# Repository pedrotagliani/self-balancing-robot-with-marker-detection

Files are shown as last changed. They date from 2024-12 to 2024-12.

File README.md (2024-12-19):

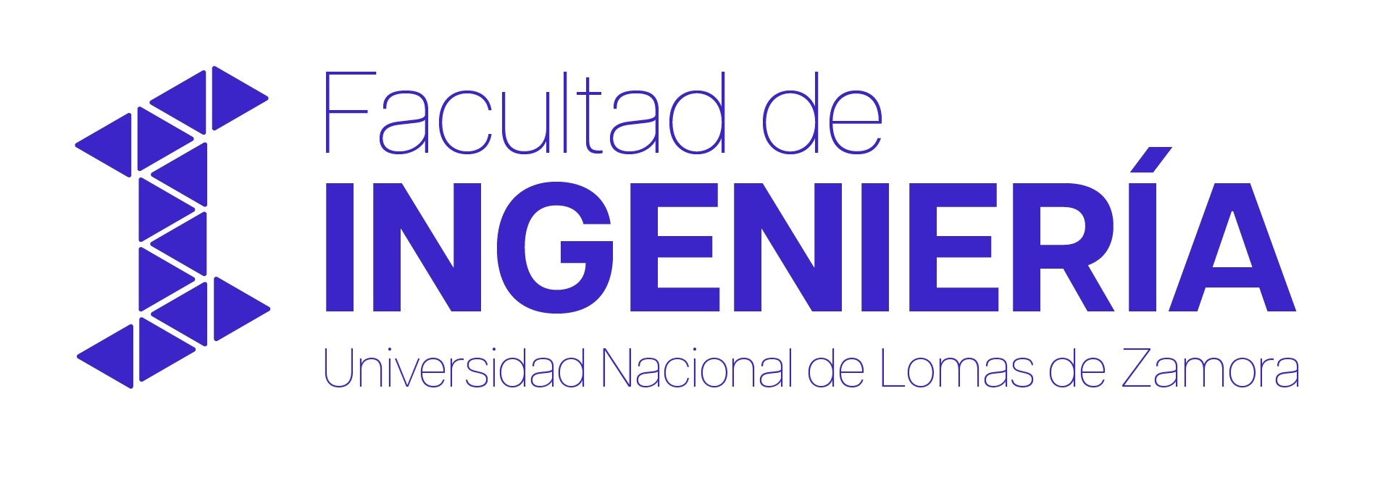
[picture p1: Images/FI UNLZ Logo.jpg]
FI UNLZ


<h1 align="center">Robot balanceador con detección de marcadores ArUco</h1>

<p>
En este proyecto, se diseñó y construyó un robot balanceador con dos funcionalidades principales. En primer lugar, se implementó un sistema de control remoto mediante una aplicación móvil, que permite mover el robot libremente en cualquier dirección. En segundo lugar, se desarrolló un sistema de equilibrio dinámico que utiliza una cámara para detectar marcadores ArUco y avanzar automáticamente cuando identifica uno en la imagen capturada.

El sistema de control de balance se basó en un controlador PID, ajustado para mantener al robot erguido en todo momento. Para medir el ángulo de inclinación, se utilizó un sensor MPU6050, que combina acelerómetro y giroscopio. Los datos obtenidos por este sensor fueron procesados en un Arduino Nano, que calculaba las señales de control necesarias para los motores. Además, se diseñaron y fabricaron placas PCB personalizadas para integrar los componentes eléctricos del sistema de manera eficiente.

El robot utilizó dos motores paso a paso NEMA 17, seleccionados por su precisión y torque, junto con controladores Pololu A4988 que gestionaron la dirección y velocidad de los motores. Para la comunicación remota, se incorporó un módulo Bluetooth HC-05, que permitió manejar el robot desde una aplicación móvil con una interfaz tipo joystick, facilitada por la biblioteca BalancingWii. Este sistema proporcionó un control intuitivo y responsivo del robot mediante una conexión estable y confiable.

El equilibrio dinámico se logró gracias al controlador PID, que ajustaba de manera constante la velocidad de los motores en función de la inclinación detectada por el sensor. Este algoritmo permitió que el robot se adaptara rápidamente a cambios en el terreno o a variaciones en su carga, manteniéndose estable en diversas condiciones.

En un segundo código, se integraron nuevas funcionalidades para dotar al robot de mayor autonomía mediante el uso de una cámara ESP32-CAM. Este sistema permitió que el robot identificara marcadores ArUco en su entorno y actuara en consecuencia. La comunicación entre el ESP32-CAM y un script en Python, ejecutado en una computadora, se estableció a través de WiFi, utilizando una URL específica para acceder a las imágenes capturadas.

El script en Python procesa estas imágenes en tiempo real, tras realizar la calibración de la cámara mediante tableros ChArUco. Posteriormente, se emplean funciones avanzadas de OpenCV para detectar marcadores ArUco en las imágenes procesadas.

Finalmente, este script se conecta con el robot mediante Bluetooth, permitiendo que el robot recibiera alertas cada vez que se detectaba un marcador en las imágenes. Con esta información, el robot avanzaba de manera autónoma hacia el marcador identificado, logrando un desplazamiento eficiente y preciso hacia el objetivo.
</p>

Robot balanceador

---

## Integrantes
- Daiana Belén Viscarra Hernández.
- Pedro Tagliani.

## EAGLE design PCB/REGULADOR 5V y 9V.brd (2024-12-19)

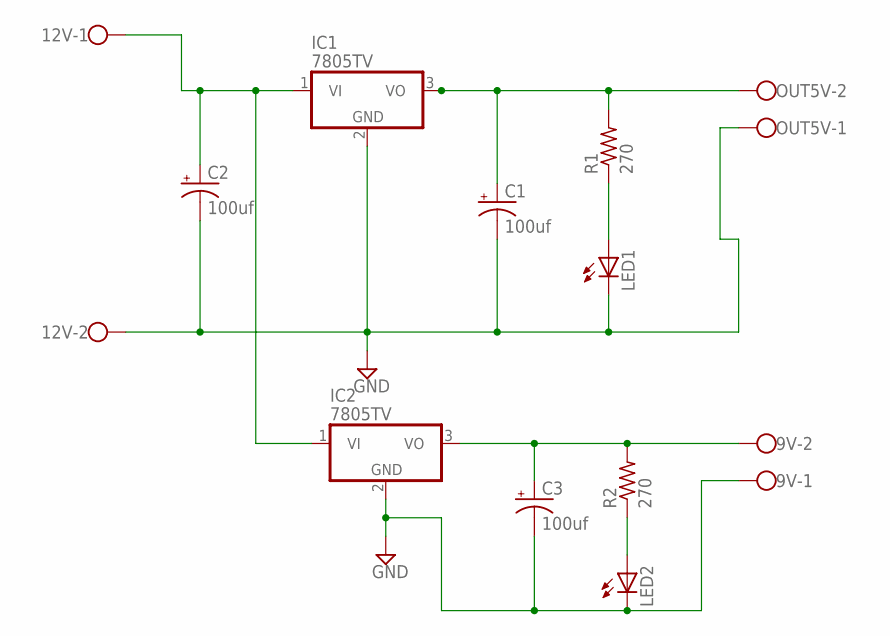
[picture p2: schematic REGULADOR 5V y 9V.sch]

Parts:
9V, 12V: W237-102
C1, C2, C3: 100uf; E2,5-5
IC1, IC2: 7805TV; TO220V
LED1, LED2: LED5MM
OUT5V: W237-102
R1, R2: 270; 0204/7

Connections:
GND: 9V.1, 12V.2, C1.-, C2.-, C3.-, IC1.2 (GND), IC2.2 (GND), LED1.K (C), LED2.K (C), OUT5V.1
unnamed: 12V.1, C2.+, IC1.1 (VI), IC2.1 (VI)
unnamed: C1.+, IC1.3 (VO), OUT5V.2, R1.2
unnamed: LED1.A, R1.1
unnamed: 9V.2, C3.+, IC2.3 (VO), R2.2
unnamed: LED2.A, R2.1

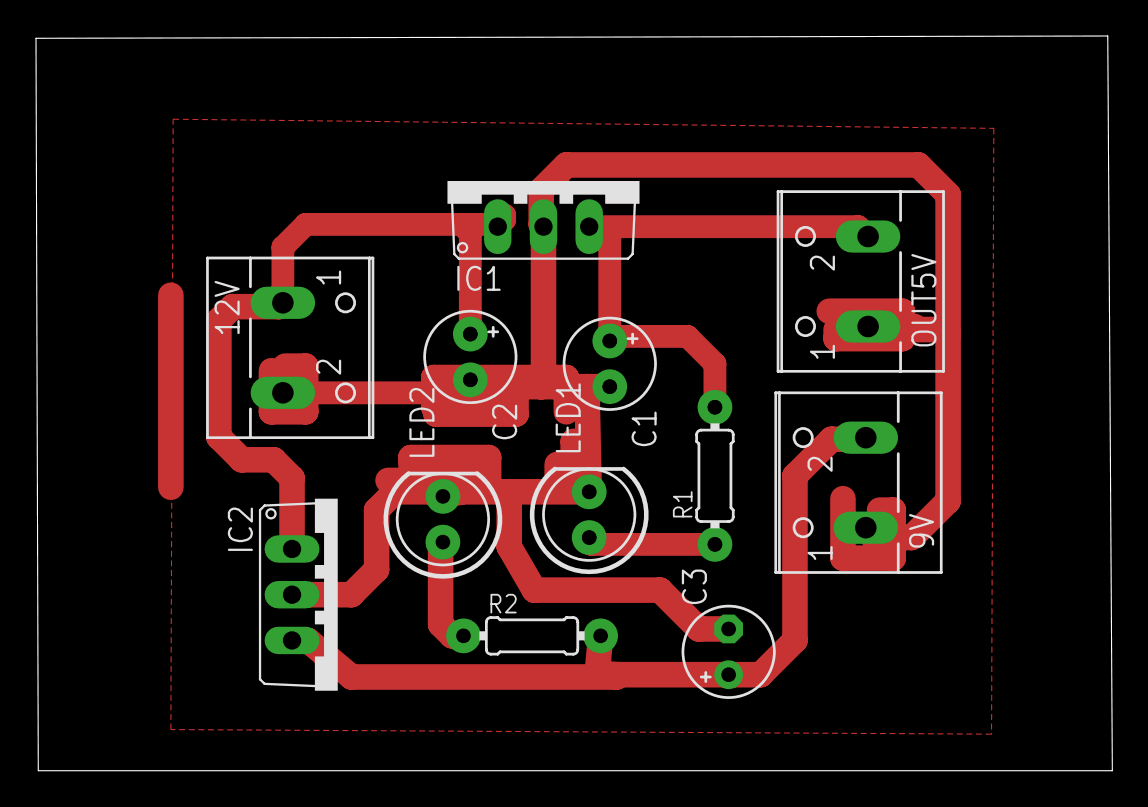
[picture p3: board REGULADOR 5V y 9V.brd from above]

Board: 2 copper layers, 59.8 x 40.8 mm, 12 parts (0 on the bottom side), 6 nets.

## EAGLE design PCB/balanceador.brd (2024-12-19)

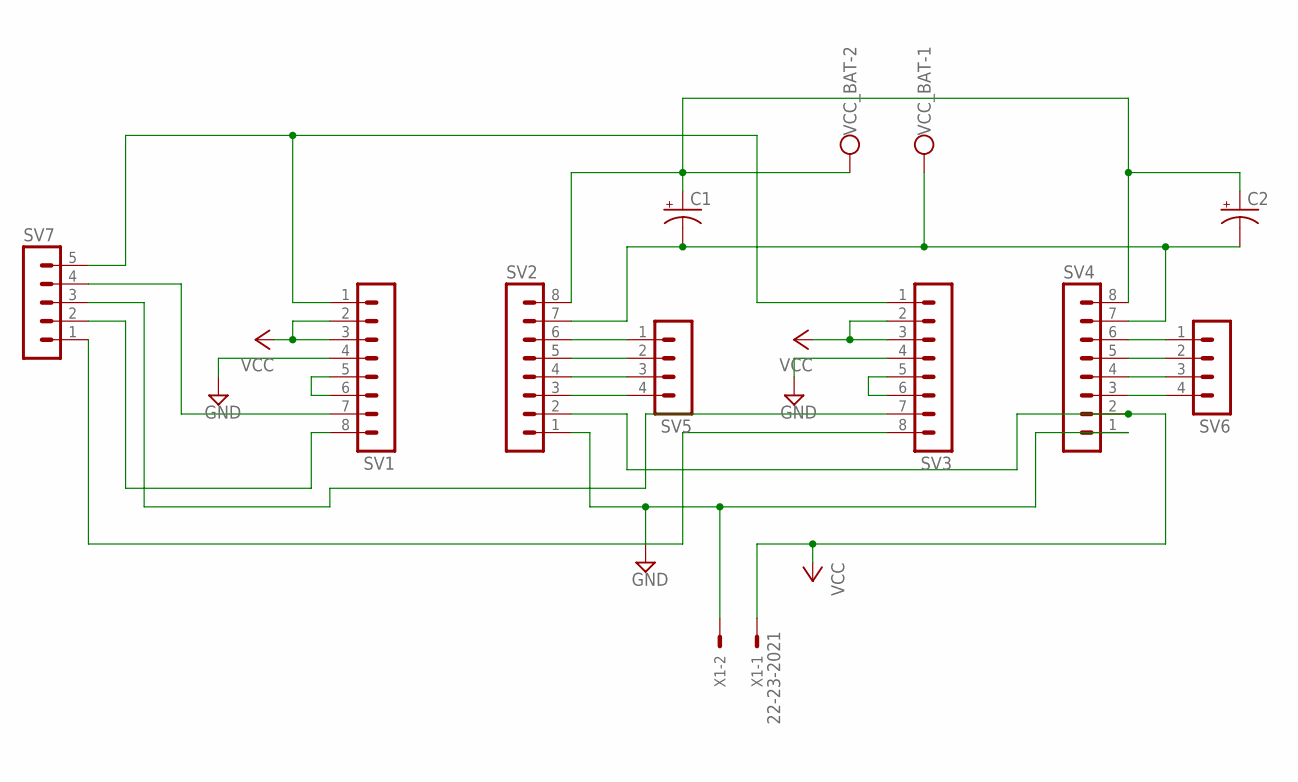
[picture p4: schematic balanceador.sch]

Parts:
C1, C2: CPOL-USE2.5-6; E2,5-6
SV1, SV2, SV3, SV4: MA08-1
SV5, SV6: MA04-1
SV7: MA05-1
VCC_BAT: W237-102
X1: 22-23-2021

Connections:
GND: SV1.4, SV2.1, SV3.4, SV4.1, X1.2
unnamed: SV2.6, SV5.1
unnamed: SV2.5, SV5.2
unnamed: SV2.4, SV5.3
unnamed: SV2.3, SV5.4
unnamed: SV4.6, SV6.1
unnamed: SV4.5, SV6.2
unnamed: SV4.4, SV6.3
unnamed: SV4.3, SV6.4
unnamed: SV3.5, SV3.6
unnamed: C1.+, C2.+, SV2.8, SV4.8, VCC_BAT.2
unnamed: SV1.5, SV1.6
unnamed: C1.-, C2.-, SV2.7, SV4.7, VCC_BAT.1
unnamed: SV1.8, SV7.2
unnamed: SV1.1, SV3.1, SV7.5
unnamed: SV3.8, SV7.1
unnamed: SV1.7, SV7.4
unnamed: SV3.7, SV7.3
VCC: SV1.2, SV1.3, SV2.2, SV3.2, SV3.3, SV4.2, X1.1

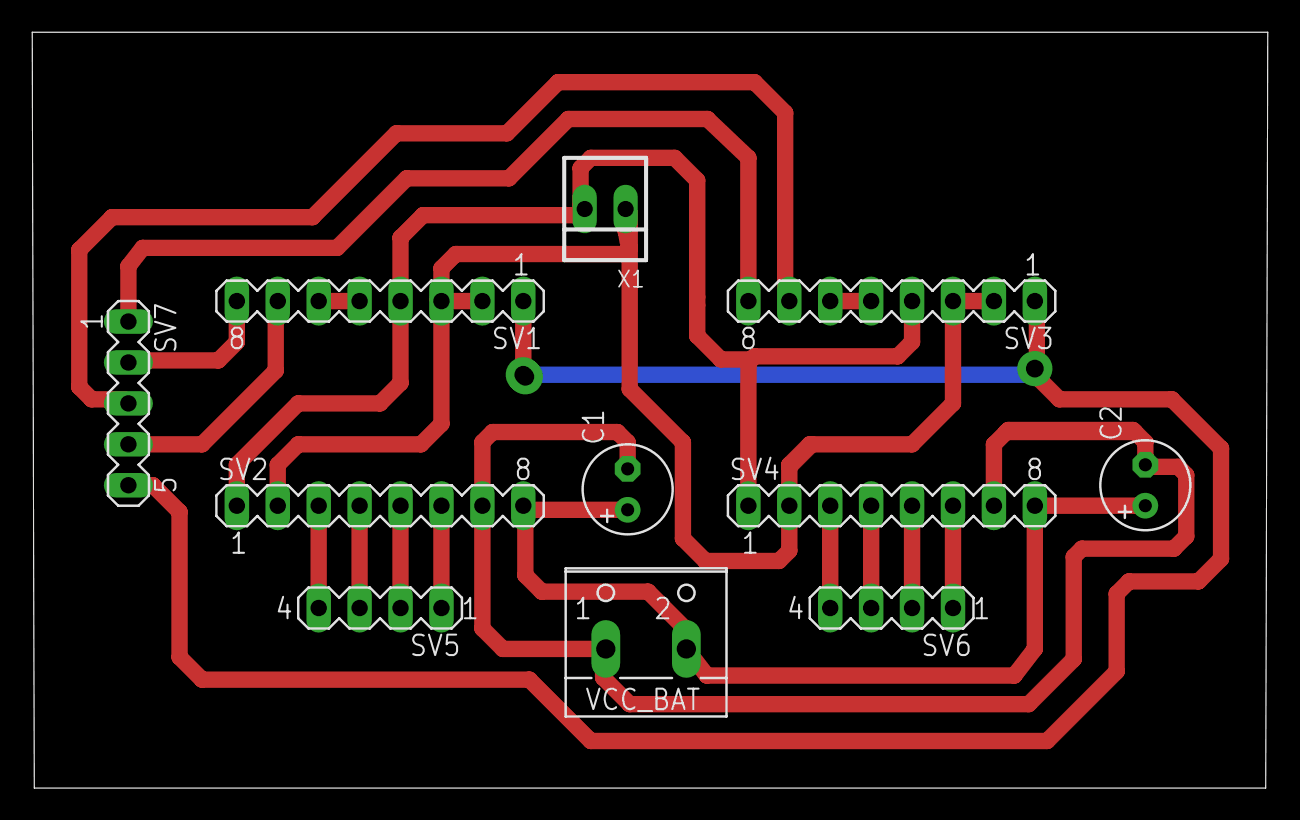
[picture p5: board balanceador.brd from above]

Board: 2 copper layers, 76.7 x 46.9 mm, 11 parts (0 on the bottom side), 19 nets.

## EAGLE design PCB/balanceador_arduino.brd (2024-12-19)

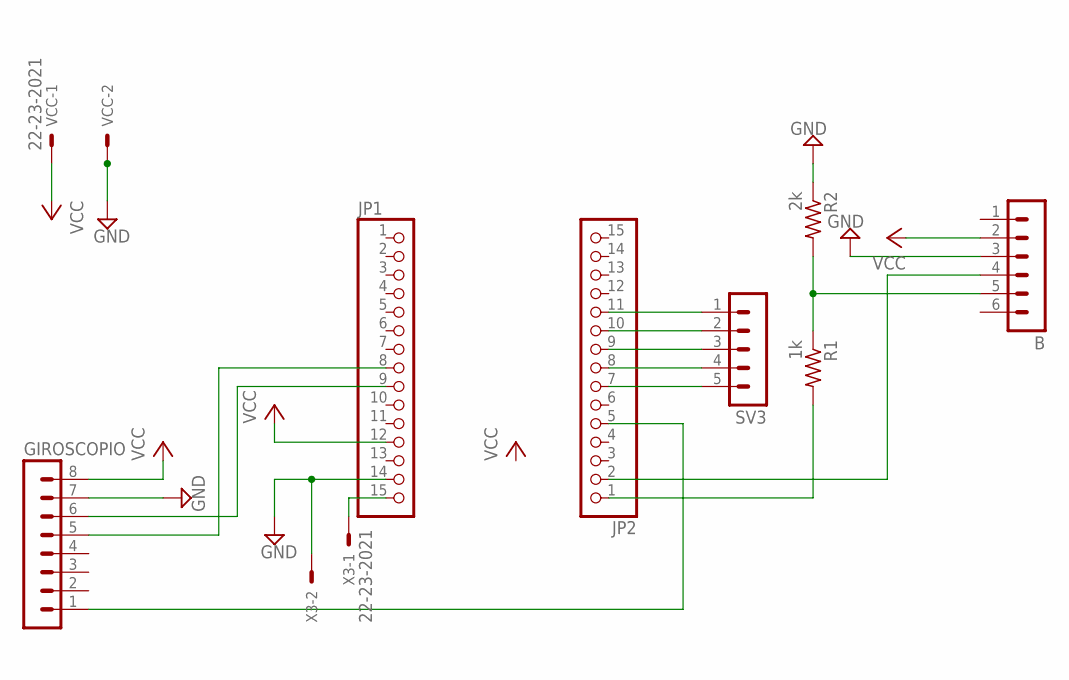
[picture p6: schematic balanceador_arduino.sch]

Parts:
B: MA06-1
GIROSCOPIO: MA08-1
JP1, JP2: PINHD-1X15; 1X15
R1: 1k; 0204/7
R2: 2k; 0204/7
SV3: MA05-1
VCC: 22-23-2021
X3: 22-23-2021

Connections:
D4: JP2.7, SV3.5
GND: B.3, GIROSCOPIO.7, JP1.14, R2.1, VCC.2, X3.2
unnamed: B.5, R1.1, R2.2
unnamed: GIROSCOPIO.6, JP1.9
unnamed: GIROSCOPIO.5, JP1.8
unnamed: JP2.1, R1.2
unnamed: B.4, JP2.2
unnamed: GIROSCOPIO.1, JP2.5
unnamed: JP2.8, SV3.4
unnamed: JP2.9, SV3.3
unnamed: JP2.10, SV3.2
unnamed: JP2.11, SV3.1
unnamed: JP1.15, X3.1
VCC: B.2, GIROSCOPIO.8, JP1.12, VCC.1

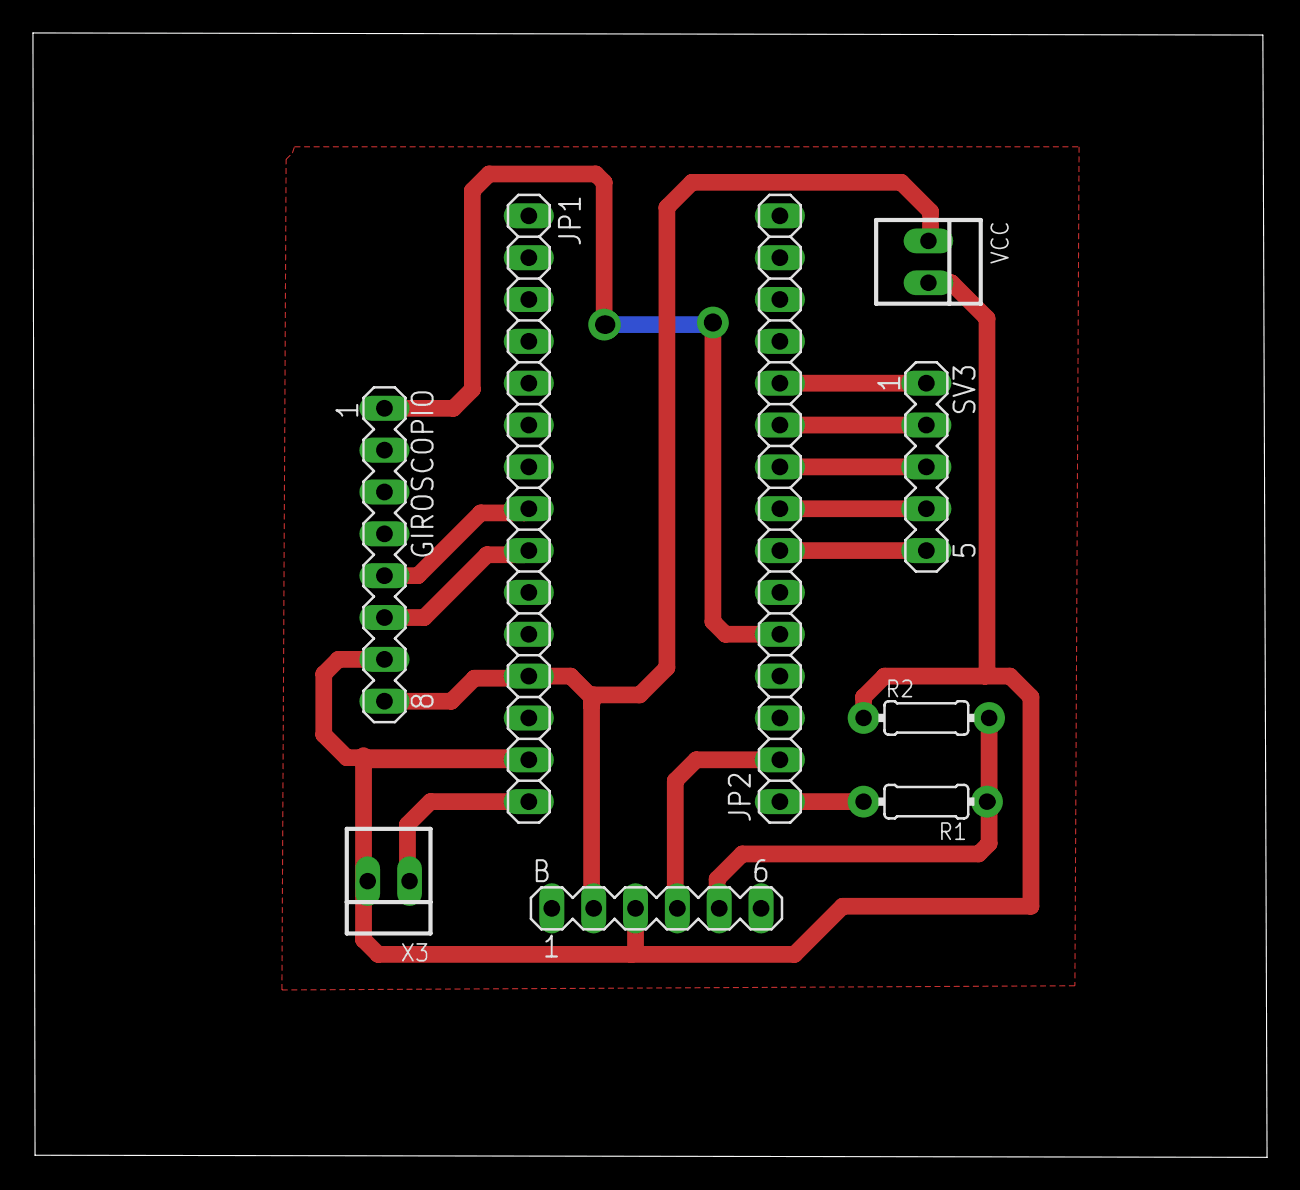
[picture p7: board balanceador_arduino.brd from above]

Board: 2 copper layers, 74.9 x 68.2 mm, 9 parts (0 on the bottom side), 14 nets.

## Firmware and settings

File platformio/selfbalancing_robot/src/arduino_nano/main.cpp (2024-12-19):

#include <Arduino.h>
// #include <SoftwareSerial.h>
#include <Wire.h>
#include "MPU6050_6Axis_MotionApps20.h"
#include "I2Cdev.h"
#include <PID_v1.h>

// Functions declaration
int deg_to_steps(float degAngle);
float pitch();
void processBluetoothData(String data);
bool check_mpu();

// Create an instance of SoftwareSerial class
// SoftwareSerial bluetoothModule(14, 15); // RX, TX
// RX pin from bluetooth module connects to TX pin (14 ---> A0) from Arduino Uno
// TX pin from bluetooth module connects to RX pin (15 ---> A1) from Ardino Uno

// Stepper 1 (motor[0]) ---> Left motor
// Stepper 2 (motor[1]) ---> Right motor

// Nema 17 stepper 1 pins
#define STEP_PIN1 5 // PORTD, bit 5
#define DIR_PIN1 7 // PORTD, bit 7

// Nema 17 stepper 2 pins
#define STEP_PIN2 6 // PORTD, bit 6
#define DIR_PIN2 8 // PORTB, bit 0

#define ENA_PIN 4

#define ZERO_SPEED 65535
#define MAX_ACCEL 4

#define RAD2GRAD 57.2957795
#define GRAD2RAD 0.01745329251994329576923690768489

#define CLR(x,y) (x&=(~(1<<y)))
#define SET(x,y) (x|=(1<<y))

// 1/16 microstepping variables
// #define STEPS_PER_REVOLUTION 3200
// #define DEGREES_PER_STEP 0.1125

// Full stepping variables
// #define STEPS_PER_REVOLUTION 200
// #define DEGREES_PER_STEP 1.8

// 1/8 microstepping variables
#define STEPS_PER_REVOLUTION 1600.0
#define DEGREES_PER_STEP 0.225

// 1/4 microstepping variables
// #define STEPS_PER_REVOLUTION 800
// #define DEGREES_PER_STEP 0.45

// Create an instance of MPU6050 class
// class default I2C address is 0x68
// specific I2C addresses may be passed as a parameter here
// AD0 low = 0x68
// AD0 high = 0x69
MPU6050 mpu(0x68);
//MPU6050 mpu(0x69); // <-- use for AD0 high

// MPU6050 resources:
// https://www.luisllamas.es/arduino-orientacion-imu-mpu-6050/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
// https://wired.chillibasket.com/2015/01/calibrating-mpu6050/
// https://www.luisllamas.es/medir-la-inclinacion-imu-arduino-filtro-complementario/
// https://github.com/nzipin/Self-Balancing-Robot/tree/master
// https://www.sinaptec.alomar.com.ar/2017/10/tutorial-23-esp8266-obtener-inclinacion.html

// Interrupt pin from MPU6050
// If new data is available, the MPU6050 will send a pulse on this interrupt pin
#define INTERRUPT_PIN 2

/*---MPU6050 Control/Status Variables---*/
bool DMPReady = false;  // Set true if DMP init was successful
uint8_t MPUIntStatus;   // Holds actual interrupt status byte from MPU
uint8_t devStatus;      // Return status after each device operation (0 = success, !0 = error)
uint16_t packetSize;    // Expected DMP packet size (default is 42 bytes)
uint8_t FIFOBuffer[64]; // FIFO storage buffer

/*---Orientation/Motion Variables---*/ 
Quaternion q;           // [w, x, y, z]         Quaternion container
VectorInt16 aa;         // [x, y, z]            Accel sensor measurements
VectorInt16 gy;         // [x, y, z]            Gyro sensor measurements
VectorInt16 aaReal;     // [x, y, z]            Gravity-free accel sensor measurements
VectorInt16 aaWorld;    // [x, y, z]            World-frame accel sensor measurements
VectorFloat gravity;    // [x, y, z]            Gravity vector
float euler[3];         // [psi, theta, phi]    Euler angle container
float ypr[3];           // [yaw, pitch, roll]   Yaw/Pitch/Roll container and gravity vector

/*-Packet structure for InvenSense teapot demo-*/ 
uint8_t teapotPacket[14] = { '$', 0x02, 0, 0, 0, 0, 0, 0, 0, 0, 0x00, 0x00, '\r', '\n' };

// Set the flag related to the interrupt (if mpuInterrupt is True, new data is available)
volatile bool MPUInterrupt  = false;
// The volatile keyword tells the compiler that a variable can be changed by something outside the normal program flow (the interrupt, in this case)

// The function to execute when the interrupt triggers
void DMPDataReady() {
    MPUInterrupt = true;
}

// PID constants
double kP = 16;
double kI = 60;
double kD = 0.5;

// PID variables
double setpoint = 0;
double input;
double output = 0;

PID pid(&input, &output, &setpoint, kP, kI, kD, DIRECT); // PID setup

unsigned long previousMillis = millis();
unsigned long currentMillis;
const long interval = 5;
// If this interval is too low (for example, interval = 1), this will case an interfereance in the measurements of the MPU6050
// And thus, will generate an undesired offset of the measurements. For example, 0° may be transformed in -6.3°, which doesn't makes sense

float lastMPUMeasurement;
bool lastMPUMeasurementInitialized = false;

int16_t motor1;
int16_t motor2;

int16_t speed_m[2];           // Actual speed of motors
uint8_t dir_m[2];             // Actual direction of steppers motors

uint16_t counter_m[2];        // counters for periods
uint16_t period_m[2][8];      // Eight subperiods 
uint8_t period_m_index[2];    // index for subperiods

// 200ns => 4 instructions at 16Mhz
void delay_200ns()  
{
  __asm__ __volatile__ (
		"nop" "\n\t"
    "nop" "\n\t"
    "nop" "\n\t"
		"nop"); 
}

// https://github.com/JJulio/b-robot/blob/master/B_ROBOT/B_ROBOT.ino

ISR(TIMER1_COMPA_vect)
{
  counter_m[0]++;
  counter_m[1]++;
  if (counter_m[0] >= period_m[0][period_m_index[0]])
    {
    counter_m[0] = 0;
    if (period_m[0][0]==ZERO_SPEED)
      return;
    if (dir_m[0])
      SET(PORTD,7);  // DIR Motor 1
    else
      CLR(PORTD,7);
    // We need to wait at lest 200ns to generate the Step pulse...
    period_m_index[0] = (period_m_index[0]+1)&0x07; // period_m_index from 0 to 7
    //delay_200ns();
    SET(PORTD,5); // STEP Motor 1
    delayMicroseconds(1);
    CLR(PORTD,5);
    }
  if (counter_m[1] >= period_m[1][period_m_index[1]])
    {
    counter_m[1] = 0;
    if (period_m[1][0]==ZERO_SPEED)
      return;
    if (dir_m[1])
      SET(PORTB,0);   // DIR Motor 2
    else
      CLR(PORTB,0);
    period_m_index[1] = (period_m_index[1]+1)&0x07;
    //delay_200ns();
    SET(PORTD,6); // STEP Motor 2
    delayMicroseconds(1);
    CLR(PORTD,6);
    }
}

// We divide into 8 subperiods to increase resolution at high speeds (small periods)
// subperiod = ((1000 % vel) * 8) / vel;
// Examples for 4 subperiods:
// 1000/260 = 3.84  subperiod = 3
// 1000/240 = 4.16  subperiod = 0
// 1000/220 = 4.54  subperiod = 2
// 1000/300 = 3.33  subperiod = 1
void calculateSubperiods(uint8_t motor)
{
  int subperiod;
  int absSpeed;
  uint8_t j;
  
  if (speed_m[motor] == 0)
    {
    for (j=0;j<8;j++)
      period_m[motor][j] = ZERO_SPEED;
    return;
    }
  if (speed_m[motor] > 0 )   // Positive speed
    {
    dir_m[motor] = 1;
    absSpeed = speed_m[motor];
    }
  else                       // Negative speed
    {
    dir_m[motor] = 0;
    absSpeed = -speed_m[motor];
    }
    
  for (j=0;j<8;j++)
    period_m[motor][j] = 1000/absSpeed;
  // Calculate the subperiod. if module <0.25 => subperiod=0, if module < 0.5 => subperiod=1. if module < 0.75 subperiod=2 else subperiod=3
  subperiod = ((1000 % absSpeed)*8)/absSpeed;   // Optimized code to calculate subperiod (integer math)
  if (subperiod>0)
   period_m[motor][1]++;
  if (subperiod>1)
   period_m[motor][5]++;
  if (subperiod>2)
   period_m[motor][3]++;
  if (subperiod>3)
   period_m[motor][7]++;
  if (subperiod>4)
   period_m[motor][0]++;
  if (subperiod>5)
   period_m[motor][4]++;
  if (subperiod>6)
   period_m[motor][2]++;
  
  // DEBUG
  /*
  if ((motor==0)&&((debug_counter%10)==0)){
    Serial.print(1000.0/absSpeed);Serial.print("\t");Serial.print(absSpeed);Serial.print("\t");
    Serial.print(period_m[motor][0]);Serial.print("-");
    Serial.print(period_m[motor][1]);Serial.print("-");
    Serial.print(period_m[motor][2]);Serial.print("-");
    Serial.println(period_m[motor][3]);
    }
  */  
}

void setMotorSpeed(uint8_t motor, int16_t tspeed)
{
  // WE LIMIT MAX ACCELERATION
  if ((speed_m[motor] - tspeed)>MAX_ACCEL)
    speed_m[motor] -= MAX_ACCEL;
  else if ((speed_m[motor] - tspeed)<-MAX_ACCEL)
    speed_m[motor] += MAX_ACCEL;
  else
    speed_m[motor] = tspeed;
  
  calculateSubperiods(motor);  // We use four subperiods to increase resolution
  
  // To save energy when its not running...
  if ((speed_m[0]==0)&&(speed_m[1]==0)) {
    digitalWrite(ENA_PIN,HIGH);   // Disable motors
  }
  else {
    digitalWrite(ENA_PIN,LOW);   // Enable motors
  }
}

void setup() {
  Serial.begin(115200);

  // delay(2000);

  pinMode(STEP_PIN1, OUTPUT);
  pinMode(DIR_PIN1, OUTPUT);
  pinMode(STEP_PIN2, OUTPUT);
  pinMode(DIR_PIN2, OUTPUT);

  digitalWrite(STEP_PIN1, LOW);
  digitalWrite(DIR_PIN1, LOW);
  digitalWrite(STEP_PIN2, LOW);
  digitalWrite(DIR_PIN2, LOW);

  pinMode(ENA_PIN, OUTPUT);

  // Disable motors
  digitalWrite(ENA_PIN, HIGH);

  pinMode(INTERRUPT_PIN, INPUT);

// https://github.com/ElectronicCats/mpu6050/issues/16
// https://github.com/ElectronicCats/mpu6050/pull/69
// https://forum.arduino.cc/t/solved-i2cdev-and-wire-hangs-or-something-electrical/575044

// Possible alternative (but also use Wire.h): https://github.com/gabriel-milan/TinyMPU6050

  #if I2CDEV_IMPLEMENTATION == I2CDEV_ARDUINO_WIRE
      Wire.begin();
      Wire.setClock(400000); // 400kHz I2C clock. Comment this line if having compilation difficulties
      Wire.setWireTimeout(3000, true); //timeout value in uSec
      // https://github.com/jrowberg/i2cdevlib/issues/543
      // https://github.com/jrowberg/i2cdevlib/issues/519
      // https://www.fpaynter.com/2020/07/i2c-hangup-bug-cured-miracle-of-miracles-film-at-11/
  #elif I2CDEV_IMPLEMENTATION == I2CDEV_BUILTIN_FASTWIRE
      Fastwire::setup(400, true);
  #endif

  // bluetoothModule.begin(115200);

  /*Initialize device*/
  Serial.println(F("Initializing I2C devices..."));
  mpu.initialize();

  /*Verify connection*/
  Serial.println(F("Testing MPU6050 connection..."));
  if(mpu.testConnection() == false){
    Serial.println("MPU6050 connection failed");
    while(true);
  }
  else {
    Serial.println("MPU6050 connection successful");
  }

  /* Initializate and configure the DMP*/
  Serial.println(F("Initializing DMP..."));
  // mpu.setRate(5); // https://github.com/ElectronicCats/mpu6050/issues/16
  devStatus = mpu.dmpInitialize();

  // Calibration values obtained (offsets)
  mpu.setXAccelOffset(935);
  mpu.setYAccelOffset(-2513);
  mpu.setZAccelOffset(1719);
  mpu.setXGyroOffset(105);
  mpu.setYGyroOffset(18);
  mpu.setZGyroOffset(93);

  /* Making sure it worked (returns 0 if so) */ 
  if (devStatus == 0) {
    // mpu.CalibrateAccel(6);  // Calibration Time: generate offsets and calibrate our MPU6050
    // mpu.CalibrateGyro(6);
    Serial.println("These are the Active offsets: ");
    mpu.PrintActiveOffsets();
    Serial.println(F("Enabling DMP..."));   //Turning ON DMP
    mpu.setDMPEnabled(true);

    /*Enable Arduino interrupt detection*/
    Serial.print(F("Enabling interrupt detection (Arduino external interrupt "));
    Serial.print(digitalPinToInterrupt(INTERRUPT_PIN));
    Serial.println(F(")..."));
    attachInterrupt(digitalPinToInterrupt(INTERRUPT_PIN), DMPDataReady, RISING);
    MPUIntStatus = mpu.getIntStatus();

    /* Set the DMP Ready flag so the main loop() function knows it is okay to use it */
    Serial.println(F("DMP ready! Waiting for first interrupt..."));
    DMPReady = true;
    packetSize = mpu.dmpGetFIFOPacketSize(); //Get expected DMP packet size for later comparison
  } 
  else {
    Serial.print(F("DMP Initialization failed (code ")); //Print the error code
    Serial.print(devStatus);
    Serial.println(F(")"));
    // 1 = initial memory load failed
    // 2 = DMP configuration updates failed
  }

  //We are going to overwrite the Timer1 to use the stepper motors
  
  // STEPPER MOTORS INITIALIZATION
  // TIMER1 CTC MODE
  TCCR1B &= ~(1<<WGM13);
  TCCR1B |=  (1<<WGM12);
  TCCR1A &= ~(1<<WGM11); 
  TCCR1A &= ~(1<<WGM10);

  // output mode = 00 (disconnected)
  TCCR1A &= ~(3<<COM1A0); 
  TCCR1A &= ~(3<<COM1B0); 
  
  // Set the timer pre-scaler
  // Generally we use a divider of 8, resulting in a 2MHz timer on 16MHz CPU
  TCCR1B = (TCCR1B & ~(0x07<<CS10)) | (2<<CS10);

  //OCR1A = 125;  // 16Khz
  //OCR1A = 100;  // 20Khz
  OCR1A = 80;   // 25Khz
  TCNT1 = 0;

  TIMSK1 |= (1<<OCIE1A);  // Enable Timer1 interrupt

  delay(10000);
  
  // Enable stepper drivers
  digitalWrite(ENA_PIN, LOW);

  // Little motor vibration to indicate that robot is ready
  // for (uint8_t k=0;k<3;k++)
  // {
  //   setMotorSpeed(0,3);
  //   setMotorSpeed(1,-3);
  //   delay(150);
  //   setMotorSpeed(0,-3);
  //   setMotorSpeed(1,3);
  //   delay(150);
  // }

  pid.SetMode(AUTOMATIC);
  pid.SetOutputLimits(-400,400);

  Serial.flush();
}

// Auxiliary bluetooth variables
char bluetoothBuffer[100];
unsigned int bufferIndex = 0;
unsigned long previousMillisBluetooth = millis();
unsigned long currentMillisBluetooth;
const long intervalBluetooth = 80;



void loop() {
  // if programming failed, don't try to do anything
  if (!DMPReady)
  {
    Serial.println("DMP not ready!");
    return;
  }

  // Adjust PID values through bluetooth
  // currentMillis = millis();
  // if (currentMillis - previousMillisBluetooth > intervalBluetooth) {
  //   previousMillisBluetooth = currentMillis;
  //   if (Serial.available() > 0) {
  //       char receivedChar = Serial.read();
  //       // Serial.println(receivedChar);
  //       if (receivedChar == '\n') {
  //           bluetoothBuffer[bufferIndex] = '\0'; // Finaliza la cadena
  //           processBluetoothData(String(bluetoothBuffer));
  //           // Serial.println(String(bluetoothBuffer));
  //           bufferIndex = 0; // Resetea el índice
  //           memset(bluetoothBuffer, '\0', sizeof(bluetoothBuffer)); // Llena todo el arreglo con '\0'
  //       } else if (bufferIndex < sizeof(bluetoothBuffer) - 1) {
  //           bluetoothBuffer[bufferIndex++] = receivedChar;
  //       }
  //   }
  //  }

  if (Serial.available() > 0) {
    String recibedData = Serial.readStringUntil('\n');

    if (recibedData == "f") {
      setpoint = 1;
      kP = 10;
      kI = 20;
      kD = 0.3;

    } else if (recibedData == "p") {
      setpoint = 0;
      kP = 16;
      kI = 60;
      kD = 0.5;
      Serial.println("ok");
    } else if (recibedData == "s") {
      setpoint = 0;
      kP = 16;
      kI = 60;
      kD = 0.5;

    }
  }

  if (mpu.dmpGetCurrentFIFOPacket(FIFOBuffer)) { // Get the Latest packet 
      mpu.dmpGetQuaternion(&q, FIFOBuffer);
      mpu.dmpGetGravity(&gravity, &q);
      mpu.dmpGetYawPitchRoll(ypr, &q, &gravity);
      // Serial.println(ypr[2] * 180/M_PI);
      // Serial.println(output);
      // Serial.println(input);
      if (lastMPUMeasurementInitialized == false) {
        lastMPUMeasurement = pitch();
        input = pitch();
        pid.Compute();
        lastMPUMeasurementInitialized = true;
      } else {
        if (pitch() < 10 + lastMPUMeasurement && pitch() > lastMPUMeasurement - 10){
          input = pitch();
          lastMPUMeasurement = pitch();
          pid.Compute();
        }
      }
  }

  if (pitch() > 25 || pitch() < -25) { // Angle threshold
    // Turn off motors. It's not possible to recover the position
    setMotorSpeed(0, 0);
    setMotorSpeed(1, 0);
  } else {
    setMotorSpeed(0, output);
    setMotorSpeed(1, -output);
  }
  // Serial.println(output);
}



int deg_to_steps(float degAngle) {
    return round(degAngle*(STEPS_PER_REVOLUTION/360.0));
    // [deg] to [steps]
    // [deg/s] to [steps/s]
    // [degs/s2] to [steps/s2]
}

// In this case, we'll use the pitch angle based on the position of the MPU6050
// This function converts the values from the accel-gyro arrays into degrees
float pitch() {
  return (ypr[2] * 180/M_PI);
}

bool check_mpu() {

  bool MPUFound = false;

  for (int tries = 0; tries < 20; tries++)
  {
    Wire.beginTransmission (0x68);
    if (Wire.endTransmission () == 0)
      {
        MPUFound = true;
        break;
      }
      delay(10);
  }
  return MPUFound;
}


void processBluetoothData(String data) {
  // Split the input string into tokens based on commas
  int kPIndex = data.indexOf("kP:");
  int kIIndex = data.indexOf("kI:");
  int kDIndex = data.indexOf("kD:");

  // Parse kP value
  if (kPIndex != -1) {
    int endIndex = data.indexOf(',', kPIndex);
    String value = data.substring(kPIndex + 3, endIndex == -1 ? data.length() : endIndex);
    kP = value.toDouble();
    pid.SetTunings(kP, kI, kD); // Update PID tunings
  }

  // Parse kI value
  if (kIIndex != -1) {
    int endIndex = data.indexOf(',', kIIndex);
    String value = data.substring(kIIndex + 3, endIndex == -1 ? data.length() : endIndex);
    kI = value.toDouble();
    pid.SetTunings(kP, kI, kD); // Update PID tunings
  }

  // Parse kD value
  if (kDIndex != -1) {
    int endIndex = data.indexOf(',', kDIndex);
    String value = data.substring(kDIndex + 3, endIndex == -1 ? data.length() : endIndex);
    kD = value.toDouble();
    pid.SetTunings(kP, kI, kD); // Update PID tunings
  }

  // Print updated PID values for debugging
  Serial.print("Updated PID values -> kP: ");
  Serial.print(kP);
  Serial.print(", kI: ");
  Serial.print(kI);
  Serial.print(", kD: ");
  Serial.println(kD);
}

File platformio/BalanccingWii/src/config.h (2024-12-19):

#ifndef CONFIG_H_
#define CONFIG_H_

/*************************************************************************************************/
/****           CONFIGURABLE PARAMETERS                                                       ****/
/*************************************************************************************************/

/* this file consists of several sections
 * to create a working combination you must at least make your choices in section 1.
 * 1 - BASIC SETUP - you must select an option in every block.
 *      this assumes you have 4 channels connected to your board with standard ESCs and servos.
 * 2 - COPTER TYPE SPECIFIC OPTIONS - you likely want to check for options for your copter type
 * 3 - RC SYSTEM SETUP
 * 4 - ALTERNATE CPUs & BOARDS - if you have
 * 5 - ALTERNATE SETUP - select alternate RX (SBUS, PPM, etc.), alternate ESC-range, etc. here
 * 6 - OPTIONAL FEATURES - enable nice to have features here (FlightModes, LCD, telemetry, battery monitor etc.)
 * 7 - TUNING & DEVELOPER - if you know what you are doing; you have been warned
 *     - (ESCs calibration, Dynamic Motor/Prop Balancing, Diagnostics,Memory savings.....)
 * 8 - DEPRECATED - these features will be removed in some future release
 */

/* Notes:
 * 1. parameters marked with (*) in the comment are stored in eeprom and can be changed via serial monitor or LCD.
 * 2. parameters marked with (**) in the comment are stored in eeprom and can be changed via the GUI
 */


/*************************************************************************************************/
/*****************                                                                 ***************/
/****************  SECTION  1 - BASIC SETUP                                                *******/
/*****************                                                                 ***************/
/*************************************************************************************************/
    
    #define CURRENT_AXIS    PITCH       // possible to choose ROLL or PITCH axis as current.
    
    //#define INVERT_CURRENT_AXIS       // invert current axis sign, i.e. instead of turning sensor board
    
    //#define REVERSE_MOTORS_DIRECTION  // reverse both motors direction

    #define MAX_SPEED           150  // should be <= 500
    #define MAX_TARGET_ANGLE    130  // where 10 = 1 degree, should be <= 15 degree (i.e. <= 150) 
    #define MAX_STEERING        90   // should be <= 100
	
    #define RISE_SPEED_K		1.0f // this coefficient means how faster robot will be during the auto rising...  should be >= 0.5 but <= 2.0
    

  /****************************    Motor minthrottle    *******************************/
    /* Set the minimum throttle command sent to the ESC (Electronic Speed Controller)
       This is the minimum value that allow motors to run at a idle speed  */
    //#define MINTHROTTLE 1300 // for Turnigy Plush ESCs 10A
    //#define MINTHROTTLE 1120 // for Super Simple ESCs 10A
    //#define MINTHROTTLE 1064 // special ESC (simonk)
    //#define MINTHROTTLE 1050 // for brushed ESCs like ladybird
    #define MINTHROTTLE 1100 // (*)

  /****************************    Motor maxthrottle    *******************************/
    /* this is the maximum value for the ESCs at full power, this value can be increased up to 2000 */
    #define MAXTHROTTLE 1900

  /****************************    Mincommand          *******************************/
    /* this is the value for the ESCs when they are not armed
       in some cases, this value must be lowered down to 900 for some specific ESCs, otherwise they failed to initiate */
    #define MINCOMMAND  1000

  /**********************************  I2C speed for old WMP config (useless config for other sensors)  *************/
    //#define I2C_SPEED 100000L     //100kHz normal mode, this value must be used for a genuine WMP
    #define I2C_SPEED 400000L   //400kHz fast mode, it works only with some WMP clones

  /***************************    Internal i2c Pullups   ********************************/
    /* enable internal I2C pull ups (in most cases it is better to use external pullups) */
    #define INTERNAL_I2C_PULLUPS

  /**************************************************************************************/
  /*****************          boards and sensor definitions            ******************/
  /**************************************************************************************/
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

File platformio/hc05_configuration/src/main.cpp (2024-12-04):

#include <Arduino.h>
#include <SoftwareSerial.h>  // Incluimos la librería  SoftwareSerial

// Create an instance of SoftwareSerial class
SoftwareSerial bluetoothModule(15, 14); // RX, TX
// RX pin from bluetooth module connects to TX pin (14 ---> A0) from Arduino Uno
// TX pin from bluetooth module connects to RX pin (15 ---> A1) from Ardino Uno

// Serial monitor           9600       Both NL & CR
// The ">" character indicates the user entered text.
// AT+NAME=name         AT+UART=115200,0,0          */
// Hold the bluetooth module's bottom button every time you send an AT command

char c=' ';
boolean NL = true;

void setup() {
Serial.begin(9600);
bluetoothModule.begin(115200);    // this is for Bluetooth in AT mode, irrespective of comms speed.
Serial.println("Serial active...enter  AT command");
}

void loop() { 
      if (bluetoothModule.available())   
    {
        c = bluetoothModule.read();
        Serial.write(c);
    }
 
    if (Serial.available())     
    {
        c = Serial.read();
        bluetoothModule.write(c);       
        if (NL) { Serial.print(">");  NL = false; }  // Echo 
        Serial.write(c);
        if (c==10) { NL = true; }
    }
}

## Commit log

2024-12-04 Stepper motors control is now performed with registers
2024-12-19 Upload PCB + Schematics
    [REGULADOR 5V y 9V.brd, REGULADOR 5V y 9V.sch, balanceador.brd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]
